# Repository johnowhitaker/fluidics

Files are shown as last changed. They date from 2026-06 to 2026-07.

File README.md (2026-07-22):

# Fluidics slide-printing tools

> **Work in progress:** this is experimental hardware and machine-control
> software. Verify generated paths, printer coordinates, temperatures, nozzle
> clearance, and Z height before running a job.

This project explores fabricating microfluidic chips by printing precise,
single-layer plastic channel walls onto glass microscope slides and thermally
bonding a coverslip on top. Background on the earlier fabrication experiments is
available in [Microfluidics, attempt 1](https://johnowhitaker.dev/mini-hw-projects/microfluidics_1.html).

## Recommended workflow: Fluidics Studio

Screenshot 2026-07-22 at 8 35 03 AM

The recommended way to design and print chips is the standalone browser-based
[Fluidics Studio](fluidics_gui/README.md) app in `fluidics_gui/`. It provides a
millimetre-accurate 75 × 25 mm editor, straight/freehand/arc/circle tools,
coverslip guides, snapping, live nozzle-path previews, full fabrication settings,
G-code generation, and direct OctoPrint upload/printing.

```sh
python3 -m venv fluidics_gui/.venv
source fluidics_gui/.venv/bin/activate
pip install -r fluidics_gui/requirements.txt
python -m fluidics_gui.app
```

Then open <http://127.0.0.1:5000>. See the
[Fluidics Studio README](fluidics_gui/README.md) for editor controls, fabrication
parameters, OctoPrint setup, and the pre-print safety checklist.

## Earlier command-line tools

The original PNG-based scripts remain available for reproducing and extending
the earlier workflow. They locate a microscope slide on an Ender 3 V3 SE bed and
generate one-layer G-code from black PNG masks.

## Files

- `cad/slide_holder.scad` - parametric OpenSCAD slide holder.
- `scripts/png_microfluidic_slicer.py` - PNG-to-preview/G-code generator.
- `examples/square.png` - simple test mask.
- `examples/t2.png` - hand-drawn test mask with multiple features.

Generated STL, preview, and G-code files go in `output/`, which is ignored by
git.

### Generate a slide trace

```sh
python3 scripts/png_microfluidic_slicer.py examples/square.png \
  --preview output/square_preview.png \
  --out-gcode output/square_slide_trace.gcode \
  --probe \
  --port-length 10 \
  --heat-park-x 158 --heat-park-y 135 --heat-park-z 25 \
  --z-height 0.2 \
  --flow 0.75 \
  --brim 2 \
  --nozzle-temp 195 \
  --offset 0.1
```

The PNG is fit to the 75 mm slide width. Black pixels are treated as the target
internal volume; red preview lines show where filament will be deposited around
that volume. The generated G-code defaults to a cold bed and can optionally probe
the slide center with `--probe`.

`--brim N` draws N concentric priming rectangles around the design before the
actual perimeter. The printer is put in relative extrusion mode (`M83`), and
generated `E` values are per-segment extrusion deltas.

Upload a generated file with:

```sh
python3 scripts/octoprint_upload.py output/square_slide_trace.gcode --select --print
```

### Drive loose Duet steppers

With the Duet connected over USB and VIN/motor power on:

```sh
python3 scripts/duet_stepper.py status
python3 scripts/duet_stepper.py move --axis X --dir forward --rotations 1 --rpm 20
python3 scripts/duet_stepper.py move --axis Y --dir reverse --rotations 0.5 --rpm 5
python3 scripts/duet_stepper.py pulse --axis X --unit microstep --count 100 --interval-ms 250
python3 scripts/duet_stepper.py pulse --axis Y --unit fullstep --count 20 --interval 1
```

The script auto-detects `/dev/cu.usbmodem*`, queries `M92` for the selected
axis, and sends relative `G1` moves with `M564 S0` so the bench motors can move
without homing. Rotation math assumes a 200 full-step motor and 16 microsteps;
override those with `--steps-per-rev` and `--microsteps` if the hardware differs.

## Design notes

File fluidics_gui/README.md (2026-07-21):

# Fluidics Studio

Fluidics Studio is a self-contained local web app for designing channel voids on a
microscope slide, previewing the exact one-layer nozzle contours, generating G-code,
and sending a verified job to OctoPrint.

It lives entirely in this directory and does not import the older project scripts.
The contouring and OctoPrint behavior were brought across and adapted for vector
designs, so this folder can be moved into its own repository later.

## Start it

From the parent `fluidics` repository:

```sh
python3 -m venv fluidics_gui/.venv
source fluidics_gui/.venv/bin/activate
pip install -r fluidics_gui/requirements.txt
python -m fluidics_gui.app
```

Then open <http://127.0.0.1:5000>. The design and printer settings autosave in the
browser. The built-in flow-focusing example makes the preview immediately useful.

If the existing Python environment already has the requirements, only the last
command is needed.

## Editor controls

- Select or move geometry with **V**. Use the inspector for exact millimetre values.
- Draw a straight channel with **L**. Hold **Ctrl** or **Command** to snap its angle
  to 45-degree increments.
- Draw freehand channels with **F**, fixed-radius arcs with **A**, circular chambers
  or ring channels with **C**, and non-printing coverslip guides with **G**.
- Toggle grid snapping and choose the grid pitch in the Design panel.
- Undo/redo with the normal platform shortcuts; duplicate with **Ctrl/Command-D**;
  delete a selected feature with **Delete**.
- Exported `.fluidics.json` files include the design, guides, and fabrication
  settings. OctoPrint credentials are deliberately excluded.

The teal geometry is the intended *fluid void*. The orange overlay is the computed
nozzle centerline around the union of that geometry. Intersections are merged before
contouring, so T-junctions and flow-focusing crosses do not acquire walls through the
middle of the junction.

## Fabrication settings

The Fabrication tab exposes the values that materially affect the generated file:

- channel-wall offset, perimeter count and spacing;
- print Z, modeled bead width, layer height, filament diameter, flow, extruder
  prime, optional tangent lead-in/lead-out length, and retraction;
- print/travel/Z feed rates, nozzle and bed temperatures, and fan percentage;
- slide origin and dimensions, homing, center probing, and probe Z offset;
- separate priming brims, heat-park position, and end-park position.

The preview and material estimate are rebuilt whenever these change. G-code uses
absolute XY positioning and relative extrusion (`M83`). Disconnected contours are
retracted and unretracted independently; brim loops are also independent paths.

## OctoPrint

Open the OctoPrint tab and enter the Pi address and an API key. **Test connection**
checks `/api/printer`. You can then upload, upload and select, or start immediately.
Starting a print requires a second confirmation that the physical setup was checked.
That confirmation can be disabled from the OctoPrint panel or permanently skipped
from the dialog; the choice is stored only in the current browser.

The address and key are stored only in this browser's local storage. They are sent to
the local Flask process when testing or uploading and are not written into design
files or server-side configuration.

## Tests

```sh
python -m pytest fluidics_gui/tests
node --check fluidics_gui/static/app.js
```

The tests cover contour unioning, disconnected paths, brims, retraction behavior,
clipping warnings, G-code downloads, and API error responses.

## Before the first hardware print

This remains experimental machine-control software. Review the orange path, download
and inspect the G-code, confirm the slide's physical X/Y origin, and validate Z height
and nozzle clearance at low risk before allowing unattended movement or heating.

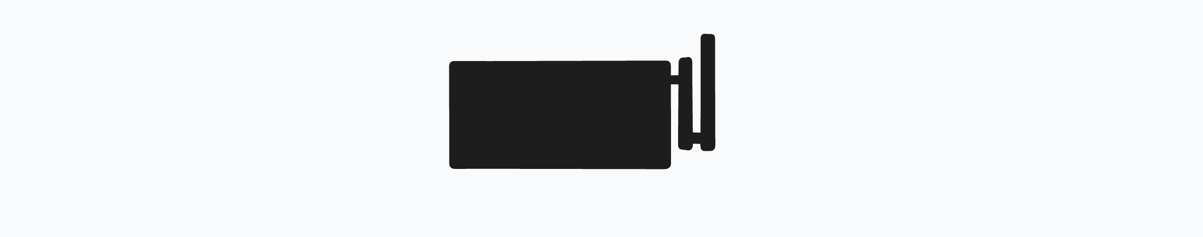
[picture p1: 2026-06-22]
examples/t2.png

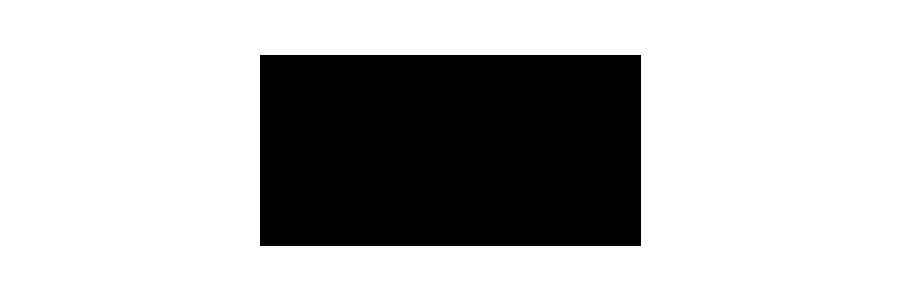
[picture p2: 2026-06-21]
examples/square.png

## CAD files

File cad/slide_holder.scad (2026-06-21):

// Loose microscope slide locator for printing directly on an Ender 3 bed.
// Units are millimeters. The slide datum is the inside lower-left corner.

$fn = 48;

slide_x = 75.0;
slide_y = 25.0;
slide_clearance = 0.9;

wall = 4.0;
base_thickness = 1.6;
clip_height = 2.2;
clip_lip = 1.0;
corner_radius = 2.0;

finger_gap = 12.0;
front_gap = 18.0;

bed_anchor_hole_d = 4.2;
bed_anchor_margin = 6.0;

inner_x = slide_x + 2 * slide_clearance;
inner_y = slide_y + 2 * slide_clearance;
outer_x = inner_x + 2 * wall;
outer_y = inner_y + 2 * wall;

module rounded_rect(size, r) {
    hull() {
        translate([r, r]) circle(r = r);
        translate([size[0] - r, r]) circle(r = r);
        translate([size[0] - r, size[1] - r]) circle(r = r);
        translate([r, size[1] - r]) circle(r = r);
    }
}

module frame_2d() {
    difference() {
        rounded_rect([outer_x, outer_y], corner_radius);
        translate([wall, wall])
            square([inner_x, inner_y], center = false);

        // Front access gap for sliding the glass in and pushing it out.
        translate([outer_x / 2 - front_gap / 2, -0.1])
            square([front_gap, wall + 0.2], center = false);

        // Side finger reliefs.
        translate([-0.1, outer_y / 2 - finger_gap / 2])
            square([wall + 0.2, finger_gap], center = false);
        translate([outer_x - wall - 0.1, outer_y / 2 - finger_gap / 2])
            square([wall + 0.2, finger_gap], center = false);
    }
}

module low_clip(x, y, rot) {
    translate([x, y, base_thickness - 0.05])
        rotate([0, 0, rot])
            linear_extrude(clip_height + 0.05)
                polygon(points = [
                    [0, 0],
                    [8, 0],
                    [8, wall],
                    [clip_lip, wall],
                    [clip_lip, wall + clip_lip],
                    [0, wall + clip_lip]
                ]);
}

module slide_holder() {
    difference() {
        union() {
            linear_extrude(base_thickness) frame_2d();

            // Four low overhangs. They should locate without pinching; shim later.
            low_clip(wall + 8, wall - clip_lip, 0);
            low_clip(outer_x - wall - 16, wall - clip_lip, 0);
            low_clip(wall + 8, outer_y - wall + clip_lip, 180);
            low_clip(outer_x - wall - 16, outer_y - wall + clip_lip, 180);

            // Raised datum nubs against the left and rear edges.
            translate([wall - 0.6, wall + 4, base_thickness])
                cube([0.8, 7, clip_height]);
            translate([wall - 0.6, outer_y - wall - 11, base_thickness])
                cube([0.8, 7, clip_height]);
            translate([wall + 4, outer_y - wall - 0.2, base_thickness])
                cube([10, 0.8, clip_height]);
            translate([outer_x - wall - 14, outer_y - wall - 0.2, base_thickness])
                cube([10, 0.8, clip_height]);
        }

        // Optional screw/tape registration holes outside the slide area.
        translate([bed_anchor_margin, bed_anchor_margin, -0.1])
            cylinder(h = base_thickness + clip_height + 0.3, d = bed_anchor_hole_d);
        translate([outer_x - bed_anchor_margin, bed_anchor_margin, -0.1])
            cylinder(h = base_thickness + clip_height + 0.3, d = bed_anchor_hole_d);
    }
}

slide_holder();

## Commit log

2026-06-21 Initial fluidics slide printing tools
    [slide_holder.scad, slide_holder.stl]
2026-06-22 Fix slide trace extrusion and ignore outputs
    [slide_holder.stl]
